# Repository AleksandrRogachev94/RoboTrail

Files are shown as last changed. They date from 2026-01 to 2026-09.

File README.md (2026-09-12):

# RoboTrail 🤖

A Raspberry Pi robot that maps a room by itself, built from parts rather than from a kit — pose-graph SLAM, frontier exploration, and a single time-of-flight rangefinder on a hobby servo standing in for a lidar. No ROS, no gmapping, no Cartographer.

<p align="center">
  <video src="https://github.com/user-attachments/assets/6f5a3e32-c5a6-42ae-8448-716495ea4b60" controls autoplay loop muted playsinline width="100%"></video>
</p>

_Autonomous run: the robot picks a frontier, drives to it, stops, sweeps the room, folds the scan into the pose graph, and repeats — camera streaming the whole time._

## What it actually does

There's no lidar here. The "lidar" is one VL53L1X time-of-flight sensor on a servo, taking 80 readings across a 180° arc every time the robot stops. Against a real spinning scanner that's a sparse, noisy, half-blind view of the room — it costs a rounding error of what a lidar does, and it makes everything downstream harder. That difficulty is most of what makes the project interesting.

Nothing came out of a box. Components were picked one at a time and wired by hand, the chassis and camera mount were modelled in CAD and printed, and every algorithm below — scan matching, the graph optimizer, the exploration planner — is written directly against numpy and scipy rather than pulled from a SLAM library.

The loop is stop-and-scan: drive one waypoint, stop, sweep, match the scan against the previous one, record it as a node in a pose graph, optimize the graph, rebuild the map from the corrected poses, pick the next frontier.

Localization is **pose-graph based, not filter based**. There's no EKF or particle filter in the running system — corrections come from ICP scan matching and joint graph optimization instead. ([EKF_GUIDE.md](EKF_GUIDE.md) is background reading from the learning path, not a description of what's running.)

> **AI assistants:** see [AI_GUIDE.md](AI_GUIDE.md) — the point of this repo is learning robotics, so teach concepts rather than writing the implementation.

## Hardware

<p align="center">
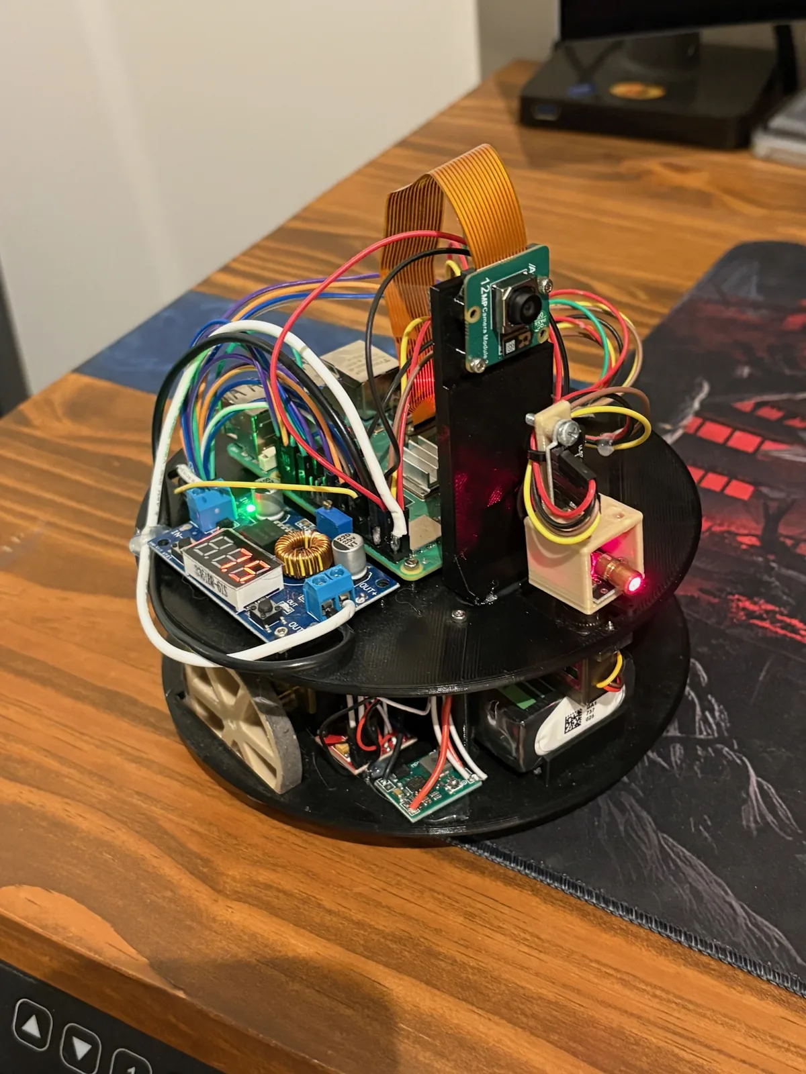
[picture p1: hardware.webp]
RoboTrail — Pi 5, camera, buck converter and ToF laser on the top plate
  
</p>

| Part | Notes |
| --- | --- |
| Raspberry Pi 5 | Runs everything on-board — SLAM, motor control, and the web server |
| Custom 3D-printed chassis | Two-tier round platform, ~155 mm across, SMARS-style tank treads |
| N20 motors + TB6612FNG | 1 kHz software PWM; quadrature encoders counted by the kernel `rotary-encoder` overlay and read over `evdev`, since Python polling drops ticks |
| VL53L1X ToF | Short-range mode, 50 ms timing budget. Readings past 250 cm are treated as "nothing there" rather than as hits |
| SG90 servo | Hardware PWM on GPIO 18 — software PWM jitters under load and smears the scan |
| MPU-6050 | Gyro Z only, integrated at 50 Hz for heading; bias re-calibrated before every move |
| Pi Camera v3 | MJPEG stream to the dashboard, on a [printed mount](cad/pi_camera_v3_mount.scad) |
| KY-008 laser | Debug aid — shows where the ToF is actually pointing |
| 2S LiPo + XL4015 | 7.4 V pack, bucked down to 5 V |

Chassis dimensions, wiring, and I2C addresses are in [CHASSIS.md](CHASSIS.md).

## How it works

**Motion.** Turn in place to face the waypoint, then drive straight. Each wheel runs a velocity PID over a feedforward term (`PWM = 17.8 + 0.07·v`), with a heading PID on top trimming the difference, all at 50 Hz on trapezoidal ramps. Pose is dead-reckoned from encoder ticks using RK2 integration against the midpoint heading.

**Mapping.** A log-odds occupancy grid at 2 cm resolution. Each scan point casts a Bresenham ray: cells along the ray lose 0.4, the cell at the hit gains 0.85, and values clamp at ±5 so the map can still be argued out of a mistake.

**Scan matching.** [`icp.py`](src/icp.py) is a hybrid point-to-line ICP. Surface normals are estimated from each map point's 6 nearest neighbours, and where they're reliable the solver constrains the scan point to lie _on_ the wall rather than on top of one specific map dot — which matters enormously when a scan is only 80 points. Where normals are unreliable it falls back to classic point-to-point SVD. Correspondences past a distance threshold get dropped, and a match ratio below 25% aborts the alignment entirely. Derivations in [ICM_SCAN_MATCHING.md](ICM_SCAN_MATCHING.md).

**Pose graph.** ([`pose_graph.py`](src/pose_graph.py), [GRAPH_SLAM_GUIDE.md](GRAPH_SLAM_GUIDE.md).) Every scan becomes a node, stored in _sensor_ frame so it can be replayed later at a corrected pose. Edges come from odometry, sequential ICP, and loop closures, each weighted by an information matrix derived from match ratio and residual error. `scipy.optimize.least_squares` with a `soft_l1` loss and a sparse Jacobian solves all poses jointly, anchored on node 0; the map is then discarded and rebuilt from the corrected trajectory. That runs every 5 nodes, or immediately when a loop closes.

Most of the work is in the guards around that pipeline:

- An ICP result that disagrees with odometry by more than 10 cm or 20° is rejected outright. Driving alongside a long blank wall, ICP hits the aperture problem — great-looking match, rotation correct, translation off by half the wall — so match quality alone can't be trusted.
- Loop closures need a 5-node gap, a candidate within 70 cm, a heading gap under 90° (with a 180° field of view, two scans facing away from each other share no visible geometry, so a confident match between them is a lie), and an ICP match ratio of 0.6+.
- Turns over 60° trigger a mid-turn scan, because a 90° turn otherwise leaves consecutive scans with almost no overlap for ICP to work with.

**Exploration.** Frontier cells — traversable cells touching unknown space — are clustered by BFS flood fill, with clusters under 30 cells dismissed as noise. Obstacles are inflated by the robot radius (7.75 cm) plus 5 cm of padding, then A\* on the 8-connected grid plans a route, simplified afterwards by line-of-sight checks. The robot drives exactly **one** waypoint per iteration and re-detects frontiers after every scan, so it never keeps chasing a frontier the last scan already resolved. When no reachable frontiers remain, the run is done.

## Web dashboard

[`web_server.py`](src/web_server.py) serves a single page: live camera feed, the occupancy grid on a canvas, and toggleable overlays for traversable space, driven trajectory, planned path, frontier clusters, pose graph nodes and edges, loop closures, and ICP corrections drawn as arrows from raw odometry to the corrected pose. Plus a pose/state HUD, live graph stats, and a PID trace from the last movement. Click the map to send the robot somewhere, or hit Explore and leave it alone.

## Running it

```bash
pip install -r requirements.txt

# on the Pi — needs root for GPIO and port 80
sudo python3 src/web_server.py
```

Then open `http://<pi-ip>` in a browser.

Most modules run standalone off-robot — see the `*_test.py` file next to each one ([`icp_test.py`](src/icp_test.py), [`pose_graph_test.py`](src/pose_graph_test.py), [`path_planner_test.py`](src/path_planner_test.py), [`frontier_test.py`](src/frontier_test.py)); they render plots rather than assert. Calibration lives in the `calibrate_*.py` scripts — ticks per cm, motor feedforward, servo zero, and ToF alignment all need redoing for a different build.

## Docs

| | |
| --- | --- |
| [LEARNING_PATH.md](LEARNING_PATH.md) | The full stage-by-stage build log, dead reckoning through visual SLAM |
| [ICM_SCAN_MATCHING.md](ICM_SCAN_MATCHING.md) | ICP from first principles |
| [GRAPH_SLAM_GUIDE.md](GRAPH_SLAM_GUIDE.md) | Pose graphs, information matrices, loop closure |
| [EKF_GUIDE.md](EKF_GUIDE.md) | Kalman filter background — not used by the current system |
| [CHASSIS.md](CHASSIS.md) | Chassis design, printing, wiring |

## License

MIT

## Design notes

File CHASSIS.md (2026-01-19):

# Chassis Design & 3D Printing Guide

Two-tier platform with tank treads for Raspberry Pi 5 SLAM robot. Design in **Fusion 360**.

```
┌─────────────────────────────┐
│   TOP PLATE                 │  ← Pi 5, sensors, OLED
├─────────────────────────────┤  ← 35mm standoffs (printed)
│   BOTTOM PLATE              │  ← Battery, motors, buck converter
└─────────────────────────────┘
        ◯═══════════◯  ← Tank treads
```

## Dimensions

| Dimension | Value | Notes |
| --- | --- | --- |
| **Chassis length** | 140mm | Fits 2S LiPo battery lengthwise |
| **Chassis width** | 100mm | Stable platform for components |
| **Plate thickness**  | 3-4mm | Rigid but lightweight |
| **Standoff height**  | 35-40mm | Clearance for battery + wiring |
| **Wheel diameter** | 32.5mm | ~2.5 cm/sec with 28BYJ-48 steppers |
| **Wheelbase** | ~90mm | Motor/idler center to center |
| **Motor from edge**  | ~25mm | Required for 45mm mounting wall |
| **Track links** | 15-17 per side | 30-34 total (std SMARS: 32) |
| **Track link pitch** | 17.4mm | Length per link (from STL) |

## Component Dimensions (for Fusion 360 CAD)

### 28BYJ-48 Stepper Motor

```
        ┌───┐ ← Shaft: 5mm with flats, 6mm tall
    ┌───┴───┴───┐
    │  ○     ○  │ ← Mounting holes: 35mm apart, M2 threads
    │    28mm   │ ← Body diameter
    └───────────┘
    Height: 19mm (body only)
    Wiring: 5-pin connector, exits from side
```

### SG90 Micro Servo

```
    ┌─────────────────┐
    │  ┌───┐          │ ← Shaft: 4.8mm, centered 5mm from edge
    ├──┤   ├──────────┤ ← Mounting tabs: 32mm total, 2mm holes
    │  └───┘          │
    └─────────────────┘
    Body: 23mm × 12mm × 22mm
    Tab thickness: 2.5mm each side
```

### Raspberry Pi 5

```
    Mounting holes: 58mm × 49mm (M2.5 standard, but M2 works)
    Board: 85mm × 56mm
    Height with heatsink: ~15mm
```

### Integrated Standoffs (Bottom Plate)

Print standoffs as part of the bottom plate—no separate pieces needed:

```
    Side view (cross-section):

            Top plate (3mm)
    ════════╪════════╪════════  ← Screws down into standoffs
            ║        ║
            ║  35mm  ║  ← Integrated standoffs
            ║        ║
    ┌───────╨────────╨───────┐
    │     Bottom plate       │  (4mm thick)
    └────────────────────────┘
```

**Standoff positions:**

- **Front standoffs:** 5mm from front edge (no motor interference)
- **Rear standoffs:** 30mm from rear edge (clears motor mounting zone)

In Fusion 360: Extrude 8mm diameter cylinders (35mm tall) from corner positions. Use 5mm inset for front corners, 30mm inset for rear corners. Add M2 screw holes (2.2mm) at the top.

### Pi Mounting Bosses (Top Plate)

The Pi needs ~5mm clearance from the plate for airflow and to avoid shorts. Print small bosses integrated into the top plate:

```
    Top plate cross-section:

    ┌────╥────────────────╥────┐
    │    ║ 5mm            ║    │  ← Bosses
    │    ╨                ╨    │
    │        [  Pi 5  ]        │  ← Board sits on bosses
    └──────────────────────────┘

    Boss: 5mm tall, 6mm diameter, M2 hole (2.2mm) centered
    Pattern: 58mm × 49mm (matches Pi mounting holes)
```

### Corner Walls for Wheels

Add small vertical walls at all 4 corners to mount drive wheels and idlers:

```
┌─────────────────────────────────┐
│▓▓│                          │▓▓│ ← Idler mounts (front)
│  │                          │  │
│  │      [flat plate]        │  │
│  │                          │  │
│▓▓│                          │▓▓│ ← Motor mounts (rear)
└─────────────────────────────────┘

Wall dimensions:
- Height: ~45mm (to fit 35mm motor mounting hole spacing + margins)
- Thickness: 2-3mm
- Position: Centered ~25mm from front/rear edges
```

**Tip:** Import SMARS corner brackets from official STL to ensure wheel alignment.

## Parts List

### All 3D Printed

| Part | Quantity | Notes |
| --- | --- | --- |
| Top plate (140×100×3mm) | 1× | With Pi bosses, servo slot, sensor holes |
| Bottom plate with standoffs | 1× | 4mm plate + 35mm integrated corner standoffs |
| Modified wheel (5mm shaft)  | 4× | Search "SMARS 28BYJ-48 wheel" |
| Track links | 40-44× | Print extras for tension adjustment |

> ⚠️ **Important:** Standard SMARS wheels are for DC motors (3mm D-shaft). The 28BYJ-48 stepper has a 5mm shaft with flats. Use modified wheels or edit the STL in Fusion 360.

### Hardware (Buy)

| Part | Quantity | Notes |
| --- | --- | --- |
| M2 × 6mm screws | 16× | For Pi, servo, plates |
| M2 × 8mm screws | 8× | For standoffs to plates |
| M2 nuts | 16× | Or use heat-set inserts |

> **M2 screw length:** 8mm works for most applications. Avoid 5mm—too short for some mounts.

## Print Settings

| Setting | Value | Notes |
| --- | --- | --- |
| **Material** | PLA or PETG | PLA easier, PETG more durable |
| **Layer height** | 0.2mm | Speed/quality balance |
| **Infill** | 20-30% | Plates need rigidity |
| **Walls** | 3 | Strong mounting holes |

**Standoffs:** Print vertically, 40-50% infill for strength.

**Track links:** Print in PLA at 100% infill (or TPU if available). Connect with 1.75mm filament scraps as pins.

## Layout

### Motor Configuration

**Use rear drive** (both motors at rear corners):

- Simpler wiring—both ULN2003 drivers together
- Symmetric and easier to debug
- Better for 140mm chassis (diagonal drive was for compact SMARS)

### Bottom Plate

Motors mount at **rear** corners. Battery runs lengthwise in the center.

```
                  FRONT
    ┌─────────────────────────────────┐
    │  ○                           ○  │  ← Standoffs (front)
    │                                 │
    │   [INA219]   [BUCK CONVERTER]   │  ← Power monitoring + regulation
    │                                 │
    │         ┌─────────────┐         │
    │         │   BATTERY   │         │  ← Battery: 130mm long
    │         │  (2S LiPo)  │         │     centered, runs front-back
    │         └─────────────┘         │
    │                                 │
    │  ┌─────┐             ┌─────┐   │
    │  │MOTOR│             │MOTOR│   │  ← Motors (rear)
    │  │ L   │             │  R  │   │
    │  └─────┘             └─────┘   │
    │  ○                           ○  │  ← Standoffs (rear)
    └─────────────────────────────────┘
                  REAR
```

### Battery Mounting

Use a 4-wall pocket to hold the battery in place:

```
Top view of battery pocket:
┌──────────────────────────────────────┐
│                                      │
│      ┌───────────────────┐           │
│      │                   │← Wall     │
│   ┌──┤                   ├──┐        │
│   │  │     BATTERY       │  │        │
│   │  │                   │  │        │
│   └──┤   ═══════════     ├──┘        │
│      │       ↑           │           │
│      └───────┼───────────┘           │
│              │                       │
│         Wire slot                    │
└──────────────────────────────────────┘

Wall height: ~15mm (just above battery thickness)
Wall thickness: 2-3mm
Wire slot: 10mm wide gap in one wall
```

### Top Plate

Servo+ToF mounts at **front center** for unobstructed 180° scanning. Pi is centered with sensors around it.

```
                  FRONT
    ┌─────────────────────────────────┐
    │  ○        [SERVO+ToF]        ○  │  ← Servo CENTER-FRONT
    │              ↑                  │     (not corner!)
    │         Scanning arc            │
    │                                 │
    │      ┌───────────────┐          │
    │      │  Raspberry    │  [OLED]  │
    │      │     Pi 5      │          │
    │      └───────────────┘          │
    │                        [IMU]    │
    │  ○                           ○  │
    └─────────────────────────────────┘
                  REAR
```

## Fusion 360 Design Tips

1. **Start with sketches**: Create top and bottom plate outlines as 2D sketches before extruding
2. **Use components**: Make each part (plate, standoff, servo mount) a separate component
3. **Parametric design**: Use parameters for key dimensions (plate size, standoff height, screw size) so you can adjust easily
4. **Check clearances**: Use section analysis to verify standoff height provides enough battery clearance
5. **Import SMARS parts**: Import the SMARS chassis STL, extract corner brackets for motor/idler mounts
6. **Export as STL**: Right-click component → Save As Mesh → STL format for slicing

### Recommended Parameters

| Parameter | Value | Description |
| --- | ----- | --- |
| `plate_length` | 140 | Overall chassis length |
| `plate_width`  | 100 | Overall chassis width |
| `standoff_h` | 35 | Standoff height |
| `screw_dia` | 2.0 | M2 screw hole diameter |
| `screw_clear`  | 2.2 | M2 clearance hole diameter |
| `front_inset`  | 5 | Front standoff inset |
| `rear_inset` | 30 | Rear standoff inset |
| `motor_inset`  | 25 | Motor center from edge |

## Checklist Before Printing

1. Print all parts and assemble track chains (18-19 links per side)
2. Mount motors to bottom plate rear using SMARS motor mount brackets
3. Press-fit wheels onto 5mm motor shafts
4. Attach idler wheels at front corners using SMARS idler mounts
5. Loop tracks around drive and idler wheels
6. Insert M2 screws through standoffs and attach to bottom plate (or let self-tap)
7. Mount battery in pocket on bottom plate
8. Mount buck converter on bottom plate
9. Attach top plate to standoffs
10. Mount Pi 5 on bosses, servo (front center), and sensors
11. Wire everything (I2C bus, motor drivers, power)

## Checklist Before Printing

- [ ] Servo mount is centered at front (not corner)
- [ ] Motors are at rear, not front
- [ ] Pi 5 mounting holes match 58×49mm pattern
- [ ] Pi bosses are 5mm tall
- [ ] Standoffs are integrated into bottom plate (35mm tall)
- [ ] Plate holes match component mounting patterns
- [ ] Wheel hub fits 5mm shaft with flats (not 3mm D-shaft)
- [ ] Battery pocket has 4 walls with wire slot
- [ ] Corner walls added for motor and idler mounts

## Resources

- [SMARS Official](https://www.smarsfan.com/) — Original design files
- [Thingiverse SMARS](https://www.thingiverse.com/thing:2662828) — STL downloads
- Search: "SMARS 28BYJ-48" for stepper-compatible wheels

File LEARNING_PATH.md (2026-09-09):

# Learning Path

The full stage-by-stage build log for RoboTrail — see [README.md](README.md) for the project overview and demo. This doc is the original from-scratch walkthrough: hardware, wiring, and every SLAM concept in the order they were actually learned and implemented, from open-loop dead reckoning up through particle filters and visual SLAM.

> **Note for AI:** Follow [AI_GUIDE.md](AI_GUIDE.md) when assisting with this project. Prioritize teaching over implementing.

## Hardware

### Core Components

| Component | Model | Purpose |
| --- | --- | --- |
| **Computer** | Raspberry Pi 5 | Main processing |
| **Chassis** | SMARS (3D printed) | Robot frame |
| **Motors** | N20 + TB6612FNG | DC motors with encoders for odometry |
| **Distance Sensor** | VL53L1X ToF | Laser ranging up to 4m (the "lidar") |
| **IMU** | MPU-6050 | Gyroscope for rotation tracking |
| **Servo** | SG90 | Pan the ToF sensor for 180° scans |

### Power System

| Component | Spec |
| --- | --- |
| **Battery** | 7.4V 5200mAh 2S LiPo |
| **Buck Converter** | XL4015 5A (with voltmeter) |
| **Safety** | Inline blade fuse (5A) |
| **Connector** | Deans/T-plug |
| **Monitoring** | INA219 (I2C voltage/current sensor) |

### Optional Extras

- **SSD1306 OLED** (0.96" I2C) — Display status, battery %, sensor data
- **KY-008 Laser** — Visual debugging (shows where ToF is pointing)

## Learning Path

**SLAM = Simultaneous Localization and Mapping**

SLAM answers two questions at once: _"Where am I?"_ (localization) and _"What does this place look like?"_ (mapping).

**Your Background:** You are comfortable with math/probability (matrices, Bayes rule) but "rusty."
**Our Approach:** We will start with a **deterministic** version (Stage 4) to build intuition for the mechanics. Once that works, we will leverage your math background to upgrade to **Probabilistic SLAM** (Stage 4.5/5), implementing proper uncertainty handling (Bayesian filters) which is the "real" way robotics is done.

**Stages 1-3** teach you the building blocks. **Stage 4** is where you actually do SLAM. **Stage 5** adds intelligence on top.

---

### Stage 1: Open-Loop Movement (Foundation)

**Goal:** Make the robot drive in a perfect 1-meter square.

**What you'll learn:** How stepper motors work, basic motor control, differential turning, the concept of dead reckoning.

- Write Python to control steppers via ULN2003
- Tune `STEPS_PER_CM` until forward distance is accurate
- Tune `STEPS_PER_DEGREE` for precise 90° turns (differential drive: one wheel forward, one backward)
- Combine straight + turn movements to close the square perfectly
- No sensors yet—pure dead reckoning (counting steps to estimate distance and rotation)

**Why it matters:** Dead reckoning is the foundation of knowing "how far did I move?" and "how much did I turn?" Even with sensors, you need this as a starting estimate.

---

### Stage 2: Virtual Scanner (Sensing)

**Goal:** Create a visual radar plot of the room.

**What you'll learn:** How ToF ranging works, polar-to-cartesian conversion, basic visualization.

- Mount VL53L1X on servo
- Sweep 180° taking measurements every 10°
- Plot with matplotlib—should show room outline

**Why it matters:** This is the "mapping" half of SLAM. You're collecting range data that becomes walls on your map.

---

### Stage 3: DC Motors & PID Control

**Goal:** Upgrade to DC motors with encoder feedback and PID control for accurate movement.

**What you'll learn:** Encoder-based odometry, PID velocity control, IMU sensor fusion, control loop architecture.

#### Hardware Changes

| Component | Purpose |
| --- | --- |
| **N20 motors with encoder** | 6V, 150RPM, AB hall encoder (~20 cm/sec at 5V) |
| **TB6612FNG driver** | Efficient H-bridge for PWM motor control |

#### Pi 5 Encoder Setup

Use kernel-level encoder counting (Python polling is too slow):

```bash
# /boot/firmware/config.txt
dtoverlay=rotary-encoder,pin_a=17,pin_b=18,relative_axis=1  # Left motor
dtoverlay=rotary-encoder,pin_a=22,pin_b=23,relative_axis=1  # Right motor
```

Read encoder position from `/dev/input/eventX` using the `evdev` library.

#### Control Architecture

For stop-and-scan SLAM, a simple **single-threaded blocking** approach works best:

```python
class MotionController:
    def move(self, distance_cm, heading):
        """Blocking: PID runs inside until distance reached."""
        target_ticks = distance_cm * TICKS_PER_CM
        start = self.encoder.total

        while (self.encoder.total - start) < target_ticks:
            # Heading PID
            correction = self.heading_pid.update(heading - self.imu.heading)

            # Velocity PIDs
            left_pwm = self.left_pid.update(self.left_enc.velocity, speed - correction)
            right_pwm = self.right_pid.update(self.right_enc.velocity, speed + correction)
            self.motors.set(left_pwm, right_pwm)

            time.sleep(0.01)  # 100 Hz

        self.motors.stop()
        # Returns when done

def slam_loop():
    motion = MotionController()
    while exploring:
        motion.move(30, heading)     # Blocking - PID runs inside
        scan = scanner.sweep_180()   # Robot stopped
        pose = icp_correct(scan)     # SLAM processing
        update_map(scan, pose)
        heading = plan_next()
```

#### Three PIDs Working Together

| PID | Input | Output | Purpose |
| --- | --- | --- | --- |
| **Left velocity**  | Left encoder rate  | Left motor PWM | Track target velocity |
| **Right velocity** | Right encoder rate | Right motor PWM | Track target velocity |
| **Heading** | IMU gyro heading | Velocity difference | Keep robot straight |

**Key difference from steppers:** Encoders tell you how far you _actually_ moved, not how far you _commanded_. This is true closed-loop control.

**Why it matters for SLAM:** Accurate odometry = better pose prediction = better scan matching = better maps.

#### Arc Movement for Path Following

The robot cannot reliably rotate in place (friction causes stuttering), so we use **arc motion** where both wheels move forward at different speeds.

**Path pipeline:**

1. **A\*** on occupancy grid → raw path
2. **Gradient descent smoothing** (Sebastian Thrun's method) → smooth waypoints
3. **Arc-to-waypoint** geometry → compute arc from current pose to next waypoint
4. **Execute arc()** → differential wheel velocities

**Key formula** - Arc to reach point (x', y') from pose (x, y, θ):

```python
# Transform target to robot frame
local_x = dx * cos(θ) + dy * sin(θ)  # forward
local_y = -dx * sin(θ) + dy * cos(θ)  # left

# Arc radius (positive = left turn)
radius = (local_x² + local_y²) / (2 * local_y)
```

**Wheel velocities for arc:**

```python
v_left  = v_center * (1 - 1/radius * track_width/2)
v_right = v_center * (1 + 1/radius * track_width/2)
```

---

### Stage 4: Occupancy Grid (This is SLAM!)

**Goal:** Build a persistent map while tracking your position.

**What you'll learn:** Occupancy grids, coordinate transforms, scan matching, the predict-correct loop.

#### The Predict-Correct Loop

SLAM continuously runs this cycle:

```
┌─────────────────────────────────────────────────────────────┐
│  1. PREDICT: "Based on my motor commands, I should be here" │
│     └─ Use: Stepper counts + Gyro heading                   │
│                          ↓                                  │
│  2. SCAN: "What do I see around me?"                        │
│     └─ Use: ToF sensor swept by servo (18 points @ 10°)     │
│                          ↓                                  │
│  3. CORRECT: "Does this scan match what the map says?"      │
│     └─ If wall in map is 2cm left of where I expected →     │
│        I must be 2cm right of where I thought               │
│                          ↓                                  │
│  4. UPDATE: Add new walls to map, mark free space           │
│                          ↓                                  │
│  5. PLAN: Where should I go next? (find unexplored area)    │
│                          ↓                                  │
│  6. MOVE: Execute movement → back to step 1                 │
└─────────────────────────────────────────────────────────────┘
```

#### How Each Sensor Is Used

| Sensor | Role in SLAM |
| --- | --- |
| **Encoders** | PREDICT: "Wheels moved 200 ticks = ~10cm" |
| **Gyro (MPU-6050)** | PREDICT: "I rotated 45° during that turn" |
| **ToF (VL53L1X)** | SCAN: "Wall is 87cm away at angle 30°" |
| **Servo** | SCAN: Points the ToF at different angles  |

#### How Scanning Works

```python
def scan():
    points = []
    for angle in range(0, 181, 10):  # 0°, 10°, 20°... 180°
        servo.angle = angle
        time.sleep(0.1)  # Let servo settle
        distance = tof.read()
        points.append((angle, distance))
    return points  # 19 points forming a semicircle view
```

Each scan gives you ~19 points. Convert to map coordinates:

```python
for angle, distance in points:
    # Convert polar (angle, distance) to cartesian (x, y)
    world_angle = robot_heading + angle  # Absolute angle
    x = robot_x + distance * cos(world_angle)
    y = robot_y + distance * sin(world_angle)
    map[x][y] = WALL  # Mark as occupied
```

#### How Correction Works (Simplified)

```python
# After scanning, compare to existing map
expected_wall_distance = map.ray_cast(robot_x, robot_y, angle)
actual_wall_distance = tof.read()

error = actual_wall_distance - expected_wall_distance
# If error > 0: wall is further than expected → I'm closer to it
# If error < 0: wall is closer than expected → I'm further from it

robot_x += error * cos(angle)  # Nudge position estimate
robot_y += error * sin(angle)
```

This is a simplified version. Real SLAM uses algorithms like:

- **ICP** (Iterative Closest Point) — matches scan points to map
- **Particle Filter** — maintains multiple position hypotheses
- **Kalman Filter** — probabilistic state estimation

For learning, start with the simple version above!

#### Handling Scan Gaps

With 10° angular resolution, walls will have gaps between points. Start simple—multiple scans from different positions naturally fill gaps as evidence accumulates. If scan matching becomes jittery, add **distance-threshold interpolation** (fill between similar-distance readings). If A\* paths clip walls, add **inflation** (mark cells near obstacles as blocked).

#### How the Robot Explores

**Frontier-Based Exploration:**

1. Find cells in the map that are "unknown" (never scanned)
2. Find "frontiers" = boundaries between known-free and unknown
3. Drive toward the nearest frontier
4. Repeat until no frontiers remain (room fully mapped)

```
Map:  ? = unknown, . = free, # = wall

  ? ? ? ? ? ?
  ? . . . ? ?    Robot sees frontier at top-right
  ? . @ . ? ?    @ = robot position
  ? . . . # ?    Drives toward "?" to explore
  ? # # # # ?
```

#### Path Planning with A\*

Once you know _where_ to go (frontier), you need to plan _how_ to get there while avoiding obstacles.

**A\* Algorithm:** Finds the shortest path on your occupancy grid.

```python
def a_star(grid, start, goal):
    open_set = PriorityQueue()
    open_set.put((0, start))
    came_from = {}
    g_score = {start: 0}

    while not open_set.empty():
        _, current = open_set.get()

        if current == goal:
            return reconstruct_path(came_from, current)

        for neighbor in get_neighbors(grid, current):
            tentative_g = g_score[current] + 1
            if tentative_g < g_score.get(neighbor, inf):
                came_from[neighbor] = current
                g_score[neighbor] = tentative_g
                f_score = tentative_g + heuristic(neighbor, goal)
                open_set.put((f_score, neighbor))

    return None  # No path found
```

**Heuristic:** Use Euclidean or Manhattan distance to the goal. A\* guarantees the shortest path if the heuristic never overestimates.

#### What You'll Build

- `occupancy_grid.py` — 2D numpy array representing the map
- `scanner.py` — Sweep servo, collect ToF readings
- `localizer.py` — Predict position, correct with scan matching
- `path_planner.py` — A\* implementation for obstacle avoidance
- `explorer.py` — Find frontiers, use A\* to plan paths
- `main.py` — The loop that ties it all together

---

### Stage 5: Extended Kalman Filter (Probabilistic)

**Goal:** Replace deterministic position tracking with probabilistic state estimation.

**What you'll learn:** Gaussian uncertainty, covariance matrices, the predict-update cycle, sensor fusion via Kalman gain.

**Why EKF?** Stage 4 uses simple correction ("nudge position by error"). This works but doesn't track _how confident_ you are. EKF maintains a probability distribution over your position—uncertainty grows when moving, shrinks when sensing.

#### The EKF Loop

```python
# State: [x, y, θ] with covariance P (3×3 matrix)

def predict(motor_command):
    # Update state estimate
    x += distance * cos(θ)
    y += distance * sin(θ)
    θ += gyro_reading

    # Uncertainty GROWS (process noise Q)
    P = F @ P @ F.T + Q

def update(scan):
    for measurement in scan:
        expected = ray_cast(x, y, θ + angle)
        innovation = measurement - expected

        # Kalman gain: balance prediction vs measurement trust
        K = P @ H.T @ inv(H @ P @ H.T + R)

        # Correct state
        state += K @ innovation

        # Uncertainty SHRINKS
        P = (I - K @ H) @ P
```

#### Key Concepts

| Concept | Meaning |
| --- | --- |
| **State vector** | `[x, y, θ]` — what we're estimating |
| **Covariance (P)** | How uncertain we are about each state variable |
| **Process noise (Q)** | How much uncertainty motion adds |
| **Measurement noise (R)** | How noisy the ToF sensor is |
| **Kalman gain (K)** | How much to trust sensor vs prediction |
| **Jacobian (F, H)** | Linearization for nonlinear models |

#### What You'll Build

- `ekf.py` — EKF state estimation class
- Modify `localizer.py` to use EKF instead of simple correction
- Tune Q and R matrices for your hardware

---

### Stage 6: Particle Filter (Multi-Hypothesis)

**Goal:** Handle ambiguous situations where EKF fails (symmetry, kidnapping, global localization).

**What you'll learn:** Monte Carlo methods, importance sampling, resampling, representing arbitrary probability distributions.

**Why Particle Filter?** EKF assumes a single Gaussian belief. If the robot could be in multiple places (identical hallways, placed in unknown location), EKF can't represent this. Particles can.

#### The Particle Filter Loop

```python
# Particles: N samples, each is (x, y, θ, weight)
particles = initialize_uniform(N=100)

def predict(motor_command):
    for p in particles:
        # Move each particle with noise
        p.x += distance * cos(p.θ) + random.gauss(0, σ_motion)
        p.y += distance * sin(p.θ) + random.gauss(0, σ_motion)
        p.θ += gyro_reading + random.gauss(0, σ_rotation)

def update(scan):
    for p in particles:
        # Score: how well does this particle explain the scan?
        p.weight = 1.0
        for angle, distance in scan:
            expected = ray_cast(p.x, p.y, p.θ + angle)
            error = (distance - expected) ** 2
            p.weight *= exp(-error / (2 * σ_sensor²))

    # Normalize weights
    total = sum(p.weight for p in particles)
    for p in particles:
        p.weight /= total

    # Resample: keep good particles, discard bad ones
    particles = resample(particles)

def get_estimate():
    # Weighted average of all particles
    return (sum(p.x * p.weight), sum(p.y * p.weight), ...)
```

#### Key Concepts

| Concept | Meaning |
| --- | --- |
| **Particle** | One hypothesis of robot pose |
| **Weight** | How likely this hypothesis is given sensor data |
| **Resampling**  | Clone good particles, delete bad ones |
| **Multimodal**  | Can represent multiple possible locations |
| **Convergence** | Particles cluster at true location over time |

#### When to Use Each

| Scenario | Use |
| --- | --- |
| Known start, building map | EKF (efficient, accurate) |
| Unknown start, known map  | Particle (global localization) |
| Kidnapped robot recovery  | Particle (redistribute hypotheses) |
| Symmetric environments | Particle (multiple hypotheses) |

#### What You'll Build

- `particle_filter.py` — Particle filter class
- Modify `localizer.py` to switch between EKF and particle mode
- Implement resampling strategies (systematic, low-variance)

#### A Note on Loop Closure

Neither EKF nor particle filters solve **loop closure** — detecting when you've returned to a previously visited area. Small scan-matching errors accumulate over time, so your map may not "close" properly:

```
Start → explore → return to start
        ↓
Map shows you 10cm away from where you actually started!
```

**Detection:** Compare current scan to stored scan from that area. High similarity = loop detected.

**Correction:** Requires **graph-based SLAM** (e.g., g2o, GTSAM) to optimize the entire trajectory. This is an advanced topic beyond the current stages but worth knowing exists.

For room-sized exploration, accumulated error is usually small enough that loop closure isn't critical. For larger spaces or repeated runs, it becomes essential.

---

### Stage 7: Semantic Localization (Advanced)

**Goal:** Recognize _where_ you are using visual landmarks.

**What you'll learn:** Object detection, landmark-based localization, loop closure.

- Run YOLO on Pi Camera
- When detecting objects (chair, door), save their location to the map
- Use landmarks for relocalization if robot gets lost

**Why it matters:** Pure geometric SLAM can get confused in similar-looking corridors. Recognizing "I see the red chair" gives absolute position references.

---

### Stage 8: Visual SLAM (Feature-Based)

**Goal:** Full camera-based SLAM using visual features instead of (or alongside) ToF.

**What you'll learn:** Feature extraction (ORB, SIFT), descriptor matching, visual odometry, bundle adjustment, loop closure detection.

**The idea:** Extract distinctive points from camera images, track them across frames to estimate motion, and build a 3D map of feature locations. This is how systems like ORB-SLAM work.

**Why it's the final stage:** Combines everything—probabilistic state estimation, sensor fusion, and now replaces the ToF "lidar" with pure vision.

---

## I2C Wiring

I2C is a 2-wire bus that lets multiple devices share the same connection. Each device has a unique address.

### Physical Connection

```
Raspberry Pi 5          All I2C Devices (shared bus)
─────────────           ─────────────────────────────
GPIO 2 (SDA) ──────────┬── VL53L1X SDA
                       ├── MPU-6050 SDA
                       ├── INA219 SDA
                       └── SSD1306 SDA

GPIO 3 (SCL) ──────────┬── VL53L1X SCL
                       ├── MPU-6050 SCL
                       ├── INA219 SCL
                       └── SSD1306 SCL

3.3V ──────────────────┬── VL53L1X VCC
                       ├── MPU-6050 VCC
                       ├── INA219 VCC
                       └── SSD1306 VCC

GND ───────────────────┬── VL53L1X GND
                       ├── MPU-6050 GND
                       ├── INA219 GND
                       └── SSD1306 GND
```

### I2C Addresses (Default)

| Device | Address |
| --- | --- |
| VL53L1X  | 0x29 |
| MPU-6050 | 0x68 |
| INA219 | 0x40 |
| SSD1306  | 0x3C |

All different, so no conflicts! Run `i2cdetect -y 1` on the Pi to see connected devices.

## Main Loop Strategy: Stop-and-Scan

```
1. Move    → Drive forward using dead reckoning + gyro correction
2. Stop    → Every 50cm, halt completely
3. Scan    → Sweep servo 180° to gather ToF measurements
4. Update  → Add walls to occupancy grid, correct position
5. Plan    → Find unexplored areas, drive toward them
```

## Key Concepts

| Concept | What It Means |
| --- | --- |
| **Dead Reckoning**  | Estimating position by counting motor steps |
| **Sensor Fusion** | Combining multiple sensors for better accuracy |
| **PID Controller**  | Feedback loop to minimize error (drift correction) |
| **Occupancy Grid**  | 2D array representing free/occupied space |
| **ZUPT** | Zero-Velocity Update—recalibrate gyro when stationary |
| **Sensor Sampling** | Read gyro/encoders at 50Hz+ to capture all motion |

> [!IMPORTANT] > **Gyro and Encoder Sampling Rate**
>
> Gyros output _instantaneous angular rate_ (deg/sec), not accumulated rotation. To know total rotation, you must integrate: `total = ∫ rate(t) dt`. If you sample too slowly, you miss rotation that happened between samples (**aliasing**).
>
> **Example:** Robot turns for 1 second, then goes straight for 1 second.
>
> - Sample at 50Hz: Captures turn → integrates to 20° ✅
> - Sample at end only: Reads 0°/s × 2s = 0° ❌
>
> **This applies to ALL algorithms** (dead reckoning, PID, EKF, particle filter). The estimation algorithm can run slowly, but sensor integration must be continuous.
>
> Similarly, DC motor encoders output pulses that must be counted at high rate (hardware interrupt or kernel driver) or pulses are lost.

## Coordinate Systems

SLAM requires converting between three coordinate frames:

```
1. SENSOR FRAME     2. ROBOT FRAME       3. WORLD FRAME
   (ToF reading)       (chassis)            (the map)

      ↑ 0°                ↑ Forward            ↑ North (Y+)
      │                   │                    │
  ←───┼───→           ←───●───→            ←───┼───→ East (X+)
      │               Robot center             │
   Servo angle        (origin)              Map origin
```

### When to Convert

| From → To | When | Formula |
| --- | --- | --- |
| Sensor → Robot | After each ToF reading | Add sensor offset `(x_tof, y_tof)` |
| Robot → World  | When adding points to map | Rotate by heading, add robot position |

### Sensor Position Matters

The ToF sensor is mounted ~7cm in front of robot center. **This offset must be corrected**, otherwise scans from different headings won't align:

```
Facing North: ToF is 7cm closer to north wall → measures 1.93m instead of 2.0m
Facing East:  ToF offset is now horizontal → measures 2.0m correctly

Without correction: same wall appears at y=1.93m and y=2.0m (7cm error!)
```

### Transformation Code

```python
# Sensor offsets (meters from robot center)
TOF_OFFSET_X = 0.0    # Centered left-right
TOF_OFFSET_Y = 0.07   # 7cm forward

def scan_point_to_world(distance, servo_angle, robot_x, robot_y, robot_heading):
    """Convert a single ToF reading to world coordinates."""
    # Sensor frame → Robot frame
    px = distance * cos(servo_angle) + TOF_OFFSET_X
    py = distance * sin(servo_angle) + TOF_OFFSET_Y

    # Robot frame → World frame (rotate + translate)
    world_x = robot_x + px * cos(robot_heading) - py * sin(robot_heading)
    world_y = robot_y + px * sin(robot_heading) + py * cos(robot_heading)
    return world_x, world_y
```

## Servo PWM on Pi 5

Software PWM causes jitter under CPU load. Use **hardware PWM** for reliable servo control:

```bash
# /boot/firmware/config.txt
dtoverlay=pwm-2chan
```

Servo must be on **GPIO 12 or 18** (PWM0) or **GPIO 13 or 19** (PWM1). Use `rpi-hardware-pwm` library:

```python
from rpi_hardware_pwm import HardwarePWM
pwm = HardwarePWM(pwm_channel=0, hz=50, chip=2)  # chip=2 for Pi 5
pwm.start(7.5)  # 7.5% = center (1.5ms pulse)
# 5% = -90°, 10% = +90°
```

**Alternative:** PCA9685 I²C servo driver ($3-5) handles timing externally—16 channels, no GPIO constraints.

## Wiring Overview

### Option A: DC Motors (N20 + TB6612FNG)

| Connection | GPIO/Pin |
| --- | --- |
| **TB6612FNG** | |
| VM | 6V motor supply |
| VCC | 3.3V |
| GND | Common ground |
| STBY | 3.3V (tie high) |
| PWMA | GPIO 12 (right speed, ~1kHz) |
| PWMB | GPIO 16 (left speed, ~1kHz) |
| AIN1 / AIN2 | GPIO 20 / 21 (right direction) |
| BIN1 / BIN2 | GPIO 25 / 24 (left direction)  |
| A01 / A02 | Right motor (red/white) |
| B01 / B02 | Left motor (red/white) |
| **Encoders** | |
| Left encoder A/B  | GPIO 17 / 27 |
| Right encoder A/B | GPIO 5 / 6 |
| Encoder VCC | 3.3V |
| Encoder GND | GND |

> [!NOTE]
> Motors use **software PWM** (lgpio) at ~1kHz to avoid conflict with the servo's hardware PWM on GPIO 18 (50Hz). BIN1/BIN2 are swapped (25/24) to correct left motor direction.

### Option B: Stepper Motors (28BYJ-48 + ULN2003)

| Connection  | GPIO |
| --- | --- |
| Left motor  | GPIO 17, 27, 22, 23 |
| Right motor | GPIO 5, 6, 13, 19 |

### Common Wiring

```
Raspberry Pi 5
├── I2C Bus (GPIO 2/3)
│   ├── VL53L1X (ToF sensor)
│   ├── MPU-6050 (IMU)
│   ├── INA219 (battery monitor)
│   └── SSD1306 (OLED display)
├── Servo (GPIO 18, hardware PWM)
├── KY-008 Laser (optional)
└── Power: 5V from XL4015 buck converter
```

## Resources

- [SMARS Robot](https://www.smarsfan.com/) — Chassis design and mods
- [VL53L1X Datasheet](https://www.st.com/resource/en/datasheet/vl53l1x.pdf)
- [MPU-6050 Guide](https://invensense.tdk.com/products/motion-tracking/6-axis/mpu-6050/)

## License

MIT

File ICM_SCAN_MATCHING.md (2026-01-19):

# ICP Scan Matching: Understanding from First Principles

This guide teaches you the ICP (Iterative Closest Point) algorithm by building intuition for the underlying mathematics. By the end, you'll understand not just _what_ to implement, but _why_ each step works.

---

## Part 1: The Problem We're Solving

Imagine you take a laser scan of a room, drive forward 20cm, and take another scan. You _think_ you moved 20cm, but wheel slip and surface variations mean you might have actually moved 18cm or 22cm. How do you figure out your _true_ motion?

**The insight**: If both scans see the same walls, you can compare them. The transformation (rotation + translation) that makes the second scan "land on top of" the first scan **is** your actual motion.

```
Scan A (before):           Scan B (after):           Aligned:
    • • • •                    • • • •                 • • • •
    •       •                  •       •               ••     ••
    •       •      ──────►     •       •    ──────►    ••     ••
    •       •                  •       •               ••     ••
    • • • •                    • • • •                 • • • •
   (fixed)                   (needs alignment)        (overlapped)
```

The challenge: we don't know which point in Scan B corresponds to which point in Scan A. This is the **correspondence problem**, and it's what makes scan matching tricky.

---

## Part 2: Rigid Transformations in 2D

Before tackling the full algorithm, let's make sure we understand how to describe motion mathematically.

### What Is a Rigid Transformation?

A **rigid transformation** preserves distances and angles—it's pure rotation and translation, no stretching or shearing. When your robot moves, it undergoes a rigid transformation.

Any rigid transformation in 2D can be described by:

- A rotation angle **θ**
- A translation vector **t = [tx, ty]ᵀ**

To transform a point **p** to a new position **p'**:

```
p' = R(θ) · p + t
```

### The Rotation Matrix

Why do we use matrices for rotation? Let's derive it from scratch.

Consider a point **p = [x, y]ᵀ**. We want to rotate it by angle θ around the origin. Using basic trigonometry:

If the original point is at angle φ and distance r from origin:

- x = r·cos(φ)
- y = r·sin(φ)

After rotating by θ, the new angle is (φ + θ), but distance r stays the same:

- x' = r·cos(φ + θ)
- y' = r·sin(φ + θ)

Using the angle addition formulas:

- cos(φ + θ) = cos(φ)cos(θ) - sin(φ)sin(θ)
- sin(φ + θ) = sin(φ)cos(θ) + cos(φ)sin(θ)

Substituting x = r·cos(φ) and y = r·sin(φ):

- x' = x·cos(θ) - y·sin(θ)
- y' = x·sin(θ) + y·cos(θ)

Writing this as a matrix equation:

```
┌ x' ┐   ┌ cos(θ)  -sin(θ) ┐   ┌ x ┐
│    │ = │                 │ · │   │
└ y' ┘   └ sin(θ)   cos(θ) ┘   └ y ┘
```

That's our rotation matrix **R(θ)**.

### Key Properties of Rotation Matrices

**Property 1: Orthogonality (Rᵀ = R⁻¹)**

Rotation doesn't stretch anything—it preserves lengths. Mathematically, this means:

```
RᵀR = I  (identity matrix)
```

This is incredibly useful because inverting a rotation is just transposing it—no expensive matrix inversion needed. To "undo" a rotation by θ, just apply R(-θ) = Rᵀ.

**Property 2: Determinant = 1**

det(R) = cos²(θ) + sin²(θ) = 1

This confirms no stretching or reflection. A reflection would have det = -1.

**Property 3: Rotations Compose by Addition**

R(θ₁) · R(θ₂) = R(θ₁ + θ₂)

You can verify this by multiplying out the matrices and using trig identities.

---

## Part 3: The ICP Algorithm Overview

ICP solves the alignment problem through iteration:

```
1. GUESS: Start with some initial transformation (often from odometry)
2. MATCH: For each point in scan B, find the closest point in scan A
3. SOLVE: Find the best transformation that aligns the matched pairs
4. APPLY: Transform scan B by this transformation
5. REPEAT: Go back to step 2, using the newly transformed B

Stop when the transformation becomes negligibly small (convergence).
```

Why iterate? Because step 2 (finding correspondences) depends on how well aligned the scans are. With a bad initial alignment, you get wrong correspondences. But after aligning a little, correspondences improve, which allows better alignment, and so on.

---

## Part 4: The Alignment Problem (Given Correspondences)

Let's temporarily assume someone gave us correct correspondences—matched pairs of points:

- (b₁, a₁), (b₂, a₂), ..., (bₖ, aₖ)

We want to find R and t that minimize the total squared error:

```
E(R, t) = Σᵢ || aᵢ - (R·bᵢ + t) ||²
```

This is a **least squares** problem. Let's understand why we use squared errors and how to solve it.

### Why Squared Errors?

Consider three candidate transformations with these residual errors for 4 point pairs:

| Transform | Errors | Sum of | errors | | Sum of errors² |
| --- | --- | --- | --- | --- | --- |
| T₁ | [1, 1, 1, 1] | 4 | 4 |
| T₂ | [0, 0, 0, 4] | 4 | 16 |
| T₃ | [0.5, 0.5, 0.5, 0.5] | 2 | 1 |

**Observation 1**: Sum of absolute errors treats T₁ and T₂ equally, but T₂ is worse—it has one terrible match while T₁ is consistently decent.

**Observation 2**: Squaring penalizes large errors more heavily. T₂ gets punished for having a 4-unit error.

**Observation 3**: The function E = Σ(error)² is smooth and differentiable everywhere, making it amenable to calculus-based optimization. Absolute values have a kink at zero.

**Observation 4**: If errors are Gaussian-distributed (which sensor noise often is), minimizing squared error gives the Maximum Likelihood Estimate—the most probable solution.

### Decoupling Rotation and Translation

Here's a key insight that simplifies our problem: **we can solve for rotation first, then translation falls out trivially**.

Define the centroids (centers of mass):

```
μ_a = (1/K) Σᵢ aᵢ    (centroid of the A points)
μ_b = (1/K) Σᵢ bᵢ    (centroid of the B points)
```

Define centered points:

```
a'ᵢ = aᵢ - μ_a
b'ᵢ = bᵢ - μ_b
```

**Theorem**: The optimal rotation minimizes the error between centered points, and the optimal translation is:

```
t* = μ_a - R* · μ_b
```

**Why does this work?** Think about it geometrically. After optimal alignment:

- The centroid of transformed B should land on the centroid of A
- R·μ_b + t = μ_a
- Therefore t = μ_a - R·μ_b

By centering, we remove the translation component entirely from the rotation optimization. Now we just need to find R that minimizes:

```
Σᵢ || a'ᵢ - R·b'ᵢ ||²
```

---

## Part 5: Understanding SVD (The Heart of the Solution)

Singular Value Decomposition is one of the most powerful tools in linear algebra. Let's build intuition for what it does.

### What Does a Matrix DO?

Any matrix M represents a linear transformation. When you multiply M by a vector, you're transforming that vector.

Consider what happens when you apply a 2×2 matrix to the unit circle (all vectors of length 1):

```
Unit circle → [Matrix M] → Ellipse
```

The circle gets stretched into an ellipse. This is true for _any_ matrix (except the zero matrix).

### The Geometry of SVD

SVD says any matrix M can be decomposed as:

```
M = U · Σ · Vᵀ
```

What this means geometrically:

1. **Vᵀ** rotates/reflects the input
2. **Σ** stretches along the coordinate axes
3. **U** rotates/reflects the output

```
Input      Vᵀ           Σ              U           Output
  ○   ──────────►  ○  ──────────►  ⬭  ──────────►   ⬭
circle           rotated        ellipse         rotated
                 circle         (axis-aligned)  ellipse
```

**The singular values** (diagonal of Σ) are the scaling factors—they tell you how much stretching happens in each direction.

**The columns of V** are the input directions that get mapped to the principal axes.

**The columns of U** are the output principal axes.

### Computing SVD: What's Happening?

Let's think about the 2×2 case for our matrix H (the cross-covariance matrix we'll build).

The singular values σ₁, σ₂ are the square roots of the eigenvalues of HᵀH (or HHᵀ).

Wait, what are eigenvalues? If you've forgotten:

**Eigenvalue refresher**: For a square matrix A, an eigenvector v satisfies:

```
A·v = λ·v
```

Multiplying by A just scales v by factor λ (the eigenvalue). The vector points in the same direction.

For a symmetric matrix (like HᵀH), the eigenvectors are orthogonal to each other—they form a natural coordinate system. The eigenvalues tell you how much the matrix "stretches" in each eigenvector direction.

**Connection to SVD**:

- Columns of V are eigenvectors of HᵀH
- Columns of U are eigenvectors of HHᵀ
- Singular values = √(eigenvalues of HᵀH)

In practice, you call `numpy.linalg.svd(H)` and it handles the numerical details.

### Why SVD Solves Our Rotation Problem

Here's the beautiful result. Given our centered points, define:

```
H = Σᵢ b'ᵢ · a'ᵢᵀ
```

This is called the **cross-covariance matrix**. Each term is an outer product:

```
b'ᵢ · a'ᵢᵀ = ┌ b'x ┐            ┌ b'x·a'x  b'x·a'y ┐
             │     │ · [a'x a'y] = │                 │
             └ b'y ┘            └ b'y·a'x  b'y·a'y ┘
```

Summing over all point pairs gives H.

**What does H capture?** It encodes the correlation between the two point sets. If b and a tend to point in similar directions, certain entries of H will be large and positive.

**The SVD magic**: Decompose H = UΣVᵀ. Then:

```
R* = V · Uᵀ
```

### Why Does R = VUᵀ Work?

Let me give you the intuition (not a formal proof, but enough to understand).

Remember what SVD does: H = UΣVᵀ means H takes vectors, rotates by Vᵀ, scales by Σ, then rotates by U.

We want R such that:

```
Σᵢ || a'ᵢ - R·b'ᵢ ||²  is minimized
```

Expanding and simplifying (using properties of traces and orthogonal matrices), this becomes equivalent to:

```
Maximize: trace(RᵀH)
```

The trace of a matrix is the sum of its diagonal elements—it represents a sort of "alignment score" between R and H.

Now, RᵀH = Rᵀ(UΣVᵀ). We want to maximize trace(RᵀUΣVᵀ).

Since Σ is diagonal (with positive entries), and we want to maximize the trace, we need RᵀU = V, which means R = VUᵀ.

**Physical intuition**: U captures how the A points are oriented. V captures how the B points are oriented. VUᵀ is the rotation that maps B's orientation to A's orientation.

### The Reflection Edge Case

SVD gives orthogonal matrices U and V, but orthogonal matrices can be rotations (det = +1) or reflections (det = -1).

If det(VUᵀ) = -1, we got a reflection, not a rotation. Robots don't reflect! To fix this:

```
If det(V · Uᵀ) < 0:
    Flip the sign of the last column of V
    Recompute R = V · Uᵀ
```

This gives the best rotation (not reflection).

---

## Part 6: The Correspondence Problem

We've solved alignment assuming known correspondences. But how do we find correspondences?

### Nearest Neighbor Matching

The simplest approach: for each point bᵢ in scan B, find the closest point in scan A.

```
For each bᵢ:
    corresponding[i] = argmin_j || bᵢ - aⱼ ||
```

This requires computing distances from each B point to every A point—O(N×M) operations.

**When does this work?** When scans are approximately aligned. If B is rotated 90° from A, nearest neighbors will be completely wrong.

**The bootstrap**: Use odometry as initial guess. Odometry might be off by a few cm/degrees, but it's not off by 90°. This gets us close enough for nearest neighbor to work.

### Improving Correspondences with Iteration

Even if initial correspondences are imperfect, they're "approximately right" if the initial guess is decent. Aligning with imperfect correspondences still moves scans closer together.

After alignment, correspondences improve. After a few iterations, they stabilize at the correct matching.

This is why ICP is **iterative**—each iteration improves both alignment and correspondences.

### Outlier Rejection

Some correspondences are just wrong:

- Points that don't have true matches (one scan sees a door, other doesn't)
- Sensor noise creating spurious points
- Moving objects (person walked by during one scan)

Bad correspondences corrupt the alignment. Common fixes:

**Distance threshold**: If |b - closest_a| > threshold, reject the pair. A wall hasn't moved 2 meters between scans.

**Percentage-based**: Keep only the 80% of pairs with smallest distances. Outliers tend to have larger distances.

**Statistical**: Compute mean and std of distances, reject pairs > 2 std from mean.

---

## Part 7: Point-to-Line ICP (An Improvement)

Basic ICP minimizes point-to-point distances. But think about a wall:

```
Scan A:       · · · · · · ·    (points along wall)
Scan B:         · · · · · ·    (shifted along wall)
```

Point-to-point ICP wants each B point to exactly match some A point. But if B is shifted along the wall, points might match to wrong neighbors, causing jitter.

**Point-to-line insight**: Points on a wall can slide along the wall freely—only the perpendicular distance matters.

Instead of minimizing || bᵢ - aⱼ ||², minimize:

```
( (bᵢ - aⱼ) · nⱼ )²
```

where nⱼ is the **surface normal** at aⱼ (perpendicular to the wall).

**How to get normals?** Fit a line to aⱼ and its neighbors, then take the perpendicular.

Point-to-line converges much faster because it doesn't fight against the "slide along surface" ambiguity.

---

## Part 8: Convergence and Local Minima

### Why Does ICP Converge?

Each iteration consists of:

1. Finding nearest neighbors (correspondences)
2. Computing optimal alignment

Step 2 is a closed-form optimization—it always finds the global minimum for the _current_ correspondences.

After aligning, the total error either:

- Decreases (we found a better alignment), or
- Stays the same (we're at a fixed point)

Since error is bounded below by zero and decreases each iteration, it must converge.

### Local Minima: The Catch

ICP converges to a **local** minimum, not necessarily the global minimum. If the initial guess is bad, it might converge to a wrong alignment.

```
True alignment:   Scans overlap perfectly, error ≈ 0
Local minimum:    Scans partially overlap, error > 0 but stable
```

**Mitigation strategies**:

- Good initial guess (odometry)
- Multiple restarts with different initial guesses
- Branch-and-bound or other global methods (expensive, usually unnecessary)

For your robot with odometry giving a reasonable initial guess, local minima are rarely a problem.

---

## Part 9: Putting It All Together

Here's the complete picture:

```
┌────────────────────────────────────────────────────────────────┐
│  INPUT: Scan A (reference), Scan B (to align), initial guess  │
└────────────────────────────────────────────────────────────────┘
                              │
                              ▼
┌────────────────────────────────────────────────────────────────┐
│  ITERATION LOOP:                                               │
│                                                                │
│  1. Apply current transform to B                               │
│                                                                │
│  2. For each point in B, find nearest neighbor in A            │
│     → Create correspondence pairs                              │
│     → Reject outliers (distance threshold)                     │
│                                                                │
│  3. Compute centroids μ_a, μ_b                                 │
│  4. Center the points: a'ᵢ = aᵢ - μ_a, b'ᵢ = bᵢ - μ_b         │
│  5. Build cross-covariance: H = Σᵢ b'ᵢ · a'ᵢᵀ                 │
│  6. SVD: H = UΣVᵀ                                              │
│  7. Rotation: R = VUᵀ (with reflection check)                  │
│  8. Translation: t = μ_a - R · μ_b                             │
│                                                                │
│  9. Update total transformation                                │
│  10. Check convergence (is transform negligible?)              │
│      If no → repeat from step 1                                │
│      If yes → exit loop                                        │
└────────────────────────────────────────────────────────────────┘
                              │
                              ▼
┌────────────────────────────────────────────────────────────────┐
│  OUTPUT: Final (R, t) that aligns B to A                       │
│          This represents how the robot actually moved          │
└────────────────────────────────────────────────────────────────┘
```

---

## Part 10: Connecting to Your Robot

### Scan in Robot Frame

Your ToF sensor gives readings in polar coordinates relative to the robot:

- Angle: servo position (0° to 180°)
- Distance: ToF reading

Convert to Cartesian (still in robot frame):

```
x = distance · cos(angle)
y = distance · sin(angle)
```

### What ICP Gives You

ICP returns the transformation from scan B to scan A. If:

- Scan A was taken at pose (x₁, y₁, θ₁)
- Scan B was taken at pose (x₂, y₂, θ₂)

Then ICP's (R, t) represents the motion from pose 1 to pose 2.

### Comparison with Odometry

Odometry says you moved (Δx_odo, Δy_odo, Δθ_odo).
ICP says you actually moved (R_icp, t_icp).

The difference is odometry error. You can:

1. Trust ICP completely (replace odometry estimate)
2. Fuse them (use EKF to combine both estimates)

For your slow-moving robot with decent odometry, option 1 often works fine.

---

## Part 11: Testing Strategy

### Test 1: Identity

```
A = B (identical scans)
Expected: R = I, t = [0, 0]
```

If this fails, you have a bug in the basic algorithm.

### Test 2: Pure Translation

```
B = A + [0.1, 0]  (shifted 10cm right)
Expected: t = [0.1, 0], R = I
```

Tests that translation recovery works.

### Test 3: Pure Rotation

```
B = R(15°) · A  (rotated 15°)
Expected: R = R(15°), t = [0, 0]
```

Tests that rotation recovery works. Note: rotation around origin, so t should be zero.

### Test 4: Combined Transform

```
B = R(10°) · A + [0.05, 0.03]
Expected: recover both correctly
```

### Test 5: Gaussian Noise

Add σ = 2cm noise to B (matching your VL53L1X).

```
Expected: Close to true transform, not exact
```

### Test 6: Partial Overlap

Remove 30% of points from each scan (simulating different fields of view).

```
Expected: Still converges (tests outlier handling)
```

### Test 7: Bad Initial Guess

Start with deliberately wrong initial R, t.

```
Expected: Converges if initial error is "small enough"
         May fail if initial error is too large
```

---

## Summary

The key insights to remember:

1. **ICP alternates between correspondence and alignment** because each depends on the other

2. **Alignment is a least squares problem** that minimizes squared error between matched point pairs

3. **Centering decouples rotation from translation**—solve rotation first, translation follows trivially

4. **SVD of the cross-covariance matrix gives the optimal rotation** because it captures the orientational relationship between point sets

5. **Convergence is guaranteed** (to a local minimum) because each step can only decrease error

6. **Good initialization matters** to avoid local minima—use odometry

7. **Outlier rejection prevents bad correspondences** from corrupting the solution

With this understanding, you're ready to implement ICP. Start with the simplest version (point-to-point, distance threshold for outliers), verify with synthetic tests, then add refinements as needed.

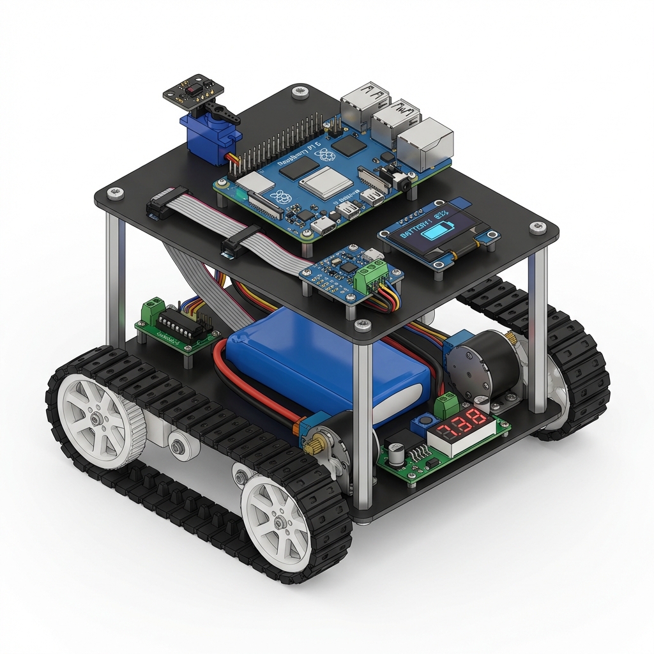
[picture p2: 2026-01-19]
chassis_prototype.png

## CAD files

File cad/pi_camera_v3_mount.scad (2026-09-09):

// Simple mount for custom Camera Module / Sensor
// Updated: Swapped horizontal and vertical camera hole orientation

$fn = 64;

// ---- Target lens center height ----
target_lens_height = 70;

// ---- Camera board mounting pattern (FLIPPED) ----
cam_hole_x   = 20.5;  // horizontal hole spacing
cam_hole_y   = 12.2;  // vertical hole spacing
cam_hole_d   = 2.2;   // M2 clearance
boss_d       = 6;     // camera standoff boss diameter
boss_h       = 3.5;   // standoff height to clear rear components

// ---- Vertical camera face ----
face_margin  = 6;
face_w       = 33;    // matches base width
face_h       = cam_hole_y + 2 * face_margin;   // 24.2mm
face_t       = 3;

// ---- Vertical riser (load-bearing column) ----
riser_w   = face_w;  // 33mm
riser_t   = 5;       // 5mm thickness
overlap   = 0.5;     // overlap for solid geometry merging

// ---- Horizontal mounting flange ----
flange_depth      = 12;   // 12mm depth
flange_t          = 3;
flange_hole_d     = 2.2;  // M2 clearance
flange_hole_inset = 8;    // inset from left/right edges

// ---- Base gussets ----
gusset_t     = 3;

// Calculate riser height:
// target_lens_height = flange_t + riser_h + face_h/2
riser_h      = target_lens_height - flange_t - face_h / 2; // 54.9mm
gusset_reach = min(riser_h, 20); // 20mm vertical leg reach

assert(riser_h > 5, "target_lens_height too small for face_h/flange_t combination");

module camera_face() {
    difference() {
        translate([-face_w/2, 0, 0])
            cube([face_w, face_t, face_h]);

        // Camera mounting holes through face and bosses
        for (dx = [-cam_hole_x/2, cam_hole_x/2])
            for (dz = [-cam_hole_y/2, cam_hole_y/2])
                translate([dx, -1, face_h/2 + dz])
                    rotate([-90, 0, 0])
                        cylinder(d = cam_hole_d, h = face_t + boss_h + 2);
    }

    // Standoff bosses on front face
    for (dx = [-cam_hole_x/2, cam_hole_x/2])
        for (dz = [-cam_hole_y/2, cam_hole_y/2])
            translate([dx, face_t, face_h/2 + dz])
                rotate([-90, 0, 0])
                    difference() {
                        cylinder(d = boss_d, h = boss_h);
                        cylinder(d = cam_hole_d, h = boss_h + 1);
                    }
}

module riser() {
    translate([-riser_w/2, 0, 0])
        cube([riser_w, riser_t, flange_t + riser_h + overlap]);
}

module mount_flange() {
    translate([-face_w/2, 0, 0])
        difference() {
            cube([face_w, flange_depth, flange_t]);

            // Center holes in the exposed flange area in front of the 5mm riser
            for (dx = [flange_hole_inset, face_w - flange_hole_inset])
                translate([dx, (flange_depth - riser_t) / 2, -1])
                    cylinder(d = flange_hole_d, h = flange_t + 2);
        }
}

module gusset(x_pos) {
    hull() {
        translate([x_pos, 0, 0]) cube([gusset_t, 0.01, 0.01]);
        translate([x_pos, flange_depth, 0]) cube([gusset_t, 0.01, 0.01]);
        translate([x_pos, 0, gusset_reach]) cube([gusset_t, 0.01, 0.01]);
    }
}

module camera_mount() {
    mount_flange();
    riser();
    translate([0, 0, flange_t + riser_h])
        camera_face();

    gusset(-riser_w/2);
    gusset(riser_w/2 - gusset_t);
}

camera_mount();

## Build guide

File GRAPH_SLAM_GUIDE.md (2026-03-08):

# Graph SLAM Guide

This guide teaches you pose graph SLAM, building on the scan-matching foundation from [ICM_SCAN_MATCHING.md](ICM_SCAN_MATCHING.md).

> [!IMPORTANT] > **Prerequisite:** You should be comfortable with ICP scan matching (Stage 4) before tackling this. Graph SLAM builds on top of ICP, not as a replacement.

---

## Part 1: Why a Pose Graph?

The current SLAM system works like this:

```
Scan → ICP match against map → Apply correction → Update map → Repeat
```

This is **greedy** — each correction is immediately committed. Two problems:

### Problem 1: Bad ICP = Permanent Damage

```
Step 1: ICP works     Step 2: ICP fails     Step 3: ICP works (but off)
┌──────────┐          ┌──────────┐          ┌──────────┐
│ ■ ■ ■ ■  │          │ ■ ■ ■ ■  │          │ ■ ■ ■ ■  │
│ ■      ■ │   ──►    │ ■      ■ │   ──►    │ ■  ■   ■ │  ← ghost wall!
│ ■  @   ■ │          │ ■    @?  │          │ ■   @  ■ │
│ ■ ■ ■ ■  │          │ ■ ■ ■ ■  │          │ ■ ■ ■ ■  │
└──────────┘          └──────────┘          └──────────┘
     OK                  Drift!               Ghosting!
```

When ICP fails at step 2, the pose drifts. Step 3's scan lands in the wrong place → ghost wall. And it's permanent — there's no undo.

### Problem 2: No Loop Closure

```
Robot explores a loop:

Start → ─ ─ ─ ─ ─ ─ ─ ─ ─ ┐
                             │
                             ↓
  ┌─ ─ ─ ─ ─ ─ ─ ─ ─ End   │
  │                          │
  └ ─ ─ ─ ─ ─ ─ ─ ─ ─ ─ ─ ─┘

End should be at Start, but accumulated drift means
the robot thinks it's 10cm away from where it began.
```

A greedy system has no way to say "I'm back at Start" and fix the whole trajectory.

### The Solution: Defer and Optimize

Instead of immediately committing each ICP correction, **record it as a constraint** and periodically find the set of poses that best satisfies ALL constraints at once.

```
Greedy:    scan → correct → commit (no going back!)

Graph:     scan → record constraint → ... → optimize all at once → rebuild map
```

---

## Part 2: The Pose Graph Structure

### Nodes and Edges

```
    Odometry         Odometry         Odometry
 N0 ═══════════► N1 ═══════════► N2 ═══════════► N3
  ║               ║               ║               ║
  ║   ICP         ║   ICP         ║   ICP         ║
  ╠───(edge)──────╣───(edge)──────╣───(edge)──────╝
  ║                                               ║
  ║              Loop closure                     ║
  ╚═══════════════════════════════════════════════╝
```

**Node** = A pose where the robot stopped and scanned.

- Stores: `(x, y, θ)` + the raw scan data

**Edge** = A constraint saying "the relative pose between these two nodes should be approximately THIS."

- Stores: measured relative transform `(dx, dy, dθ)` + how confident we are

**Three types of edges:**

| Edge | Source | Connects | Confidence |
| --- | --- | --- | --- |
| Odometry | Encoders + IMU | Consecutive nodes | Medium (wheel slip, IMU drift) |
| ICP sequential | Scan-to-scan ICP | Consecutive nodes | Variable (match quality) |
| Loop closure | Scan-to-scan ICP | Distant nodes | High (if ICP succeeds) |

### Why TWO Edges Between Consecutive Nodes?

Odometry and ICP measure the same motion differently. Having both gives the optimizer more information:

- If they agree → high confidence in the transform
- If they disagree → optimizer down-weights the less consistent one

---

## Part 3: Information Matrices (Confidence)

Each edge has an **information matrix** Ω (3×3) that says how much to trust it.

### Intuition: Springs

Think of edges as **springs** connecting nodes:

```
     Stiff spring (high Ω)         Loose spring (low Ω)
     ═══════════════════            ~~~~~~~~~~~~~~~~~~
     "I'm VERY sure about          "I'm not sure about
      this transform"                this transform"
```

When you optimize, you're finding the node positions that minimize the total spring energy. Stiff springs (high confidence edges) dominate.

This is why a bad ICP match doesn't ruin everything: it gets a loose spring, and the optimizer mostly ignores it.

### Building the Information Matrix

For a diagonal information matrix (sufficient for this project):

```
     ┌ 1/σ²_x    0       0    ┐
Ω =  │   0     1/σ²_y     0    │
     └   0       0     1/σ²_θ  ┘
```

Where σ is the standard deviation of the measurement uncertainty.

**Odometry:** σ grows with distance traveled.

```python
σ_x = σ_y = 0.05 * distance_cm   # 5% of distance
σ_θ = 0.02 * abs(rotation_deg)   # 2% of rotation
```

**ICP:** σ depends on match quality.

```python
# Good match (80% ratio, 2cm error) → tight spring
σ_x = σ_y ≈ 0.5 cm
σ_θ ≈ 1°

# Bad match (30% ratio, 8cm error) → loose spring
σ_x = σ_y ≈ 5 cm
σ_θ ≈ 10°
```

---

## Part 4: Optimization with scipy

### What the Optimizer Does

Given:

- Current poses: `[N0, N1, N2, ...]`
- Edges with measurements and information matrices

**Find** adjusted poses that minimize total weighted error:

```
E = Σ (predicted_transform - measured_transform)ᵀ Ω (predicted_transform - measured_transform)
    edge
```

This is a **nonlinear least squares** problem — exactly what `scipy.optimize.least_squares` solves.

### The Residual Function

You provide one function to scipy: `residual(poses_flat)` → returns a vector of errors.

For each edge between node i and node j:

```python
# 1. Extract poses from flat vector
xi, yi, θi = poses_flat[3*i : 3*i+3]
xj, yj, θj = poses_flat[3*j : 3*j+3]

# 2. Predicted relative transform (in node i's local frame)
dx_pred =  cos(θi) * (xj - xi) + sin(θi) * (yj - yi)
dy_pred = -sin(θi) * (xj - xi) + cos(θi) * (yj - yi)
dθ_pred = θj - θi

# 3. Error = predicted - measured
error = [dx_pred - dx_meas, dy_pred - dy_meas, normalize(dθ_pred - dθ_meas)]

# 4. Weight by sqrt of information matrix
weighted_error = sqrt(Ω) @ error
```

Stack all weighted errors into one big vector → return it.

### The normalize() Function

**Critical.** Without it, the optimizer thinks 1° and 359° are 358° apart:

```python
def normalize_angle(θ):
    return (θ + π) % (2π) - π
```

### The Anchor

If every pose can move, the whole graph can slide around while keeping edges happy. Fix node 0 to prevent this:

- Either exclude node 0's variables from the optimization vector
- Or add a very strong "prior" edge pinning it to its initial position

### Huber Loss

`scipy.optimize.least_squares(residual, x0, loss='huber')` automatically down-weights large residuals. This means:

- Normal edges → squared error (standard least squares)
- Outlier edges (bad ICP) → linear error (much less influence)

No special outlier code needed — the loss function handles it.

---

## Part 5: Loop Closure

### Detection

When the robot is near a previously visited position (but many scans ago), that's a loop closure opportunity.

```python
def find_loop_candidates(current_pose, min_gap=10, max_dist=50):
    candidates = []
    for node in graph.nodes:
        if current_node_id - node.id < min_gap:
            continue  # Too recent, skip
        if distance(current_pose, node.pose) < max_dist:
            candidates.append(node.id)
    return candidates
```

### Verification

Run scan-to-scan ICP between the current scan and the candidate's scan. If it converges with good quality → add a loop closure edge.

### The Magic

When a loop closure edge is added and we optimize, the correction **propagates backward** through the entire chain:

```
Before optimization:                After optimization:
N0 ─── N1 ─── N2 ─── N3            N0 ─── N1 ─── N2 ─── N3
                      │                     ↑      ↑      ↑
                loop closure                └──────┴──────┘
                      │             All poses shift slightly to
                      ▼             satisfy the loop closure
                     N0
```

Every node between N0 and N3 shifts a little bit to absorb the error, rather than putting all the correction on one pose.

---

## Part 6: Map Rebuild

After optimization adjusts poses, the occupancy grid is stale (built with old poses). Solution:

```python
def rebuild_map(grid, graph):
    grid.reset()  # Clear to all-unknown
    for node in graph.nodes.values():
        grid.update(node.scan_points, node.pose, free_rays=node.free_rays)
```

This is fast (Bresenham ray tracing) and guarantees a clean map with no ghosting.

When to rebuild: after every optimization call (every 5 scans).

---

## Part 7: Connecting to Your Code

### What Changes

| Component | Before (greedy) | After (graph) |
| --- | --- | --- |
| `_scan_and_update()` | ICP → apply correction → update map | ICP → add edge → (maybe optimize + rebuild) |
| Pose tracking | Modified in-place by ICP | Stored in graph nodes |
| Map | Updated incrementally | Rebuilt from graph after optimization |
| ICP target | Scan vs accumulated map | Scan vs previous scan |

### What Stays the Same

- Scanner, hardware, motion control
- Frontier detection and path planning
- Web UI (just add graph visualization data)
- A\* and occupancy grid internals

### New File Structure

```
src/
├── pose_graph.py          # [NEW] PoseNode, PoseEdge, PoseGraph + optimizer
├── graph_slam_system.py   # [NEW] GraphSlamSystem extends SlamSystem
├── slam_system.py         # [UNCHANGED] Original greedy SLAM (fallback)
├── icp.py                 # [UNCHANGED] Used for scan-to-scan matching
├── occupancy_grid.py      # [UNCHANGED] Rebuilt after optimization
└── ...
```

---

## Part 8: Implementation Order

1. **`PoseGraph` basics** — `add_node()`, `add_edge()`, `get_node()`, properties
2. **Information matrices** — `compute_odometry_info_matrix()`, `compute_icp_info_matrix()`
3. **`_normalize_angle()`** — one line but critical
4. **`_residual()`** — the core optimization function
5. **`optimize()`** — wire up scipy
6. **`rebuild_map()`** — clear + replay
7. **`GraphSlamSystem._scan_and_update()`** — integration
8. **`find_loop_candidates()`** + `_check_loop_closures()` — loop closure
9. **Test with synthetic data** before running on the robot

### Testing Strategy

Start with `pose_graph_test.py`:

```python
# Test 1: Add nodes and edges, verify they're stored correctly
# Test 2: Build a square loop with known transforms, optimize,
#          verify poses form a perfect square
# Test 3: Add one bad edge, verify Huber loss down-weights it
# Test 4: Loop closure — verify backward propagation
# Test 5: rebuild_map — verify grid matches expected
```

---

## Summary

| Concept | What It Means for Your Robot |
| --- | --- |
| **Node** | "I was HERE and saw THIS" |
| **Edge** | "Between HERE and THERE, I measured THIS transform" |
| **Information matrix** | "I'm THIS confident about that measurement" |
| **Optimize** | "Find the poses that make ALL edges happy at once" |
| **Loop closure** | "I'm back where I was 20 scans ago — fix the whole path" |
| **Rebuild** | "Replay all scans at corrected poses for a clean map" |

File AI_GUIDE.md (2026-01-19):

# AI Learning Guide

When helping with this project, prioritize **teaching over implementing**.

## Teaching Approach

### Concepts Before Code

- Start with **why** before **how**
- Use real-world analogies (e.g., "EKF is like a fuzzy blob that grows and shrinks")
- Build intuition before introducing formulas

### Math Instruction

- Explain the **purpose** of an equation before showing it
- Annotate formulas with what each variable means
- Walk through a **concrete numeric example** after the formula
- Connect math back to the robot: "So when your ToF reads 1.5m at 30°..."

### Scaffolded Learning

- Break complex problems into smaller sub-problems
- Ask questions to check understanding before proceeding
- Give algorithm structure and pseudocode, let me write real code
- Suggest what to research rather than providing all answers

### Debugging Support

- Ask what I've observed and what I expected
- Suggest debugging strategies (print statements, visualizations)
- Guide me toward the issue rather than fixing it directly

## When I Ask "How Do I Implement X?"

1. Explain what X does conceptually
2. Break into sub-problems
3. Ask which part is unclear
4. Provide structure for that part
5. Let me write the implementation

## Visuals

Use ASCII diagrams for spatial concepts and coordinate transforms. Draw before you describe.

## Pacing

Don't let me skip stages. If I try to jump ahead, remind me to complete the current stage first. Fundamentals matter.

## Goal

A developer who **understands** robotics, not a repo full of AI-written code.

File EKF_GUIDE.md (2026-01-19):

# Extended Kalman Filter Guide

This guide maps EKF concepts to the RoboTrail robot, distilled from our learning discussion.

> [!IMPORTANT] > **Sensor Sampling vs EKF Update Rate**
>
> Gyros output instantaneous rate (deg/sec), not accumulated rotation. You must sample at 50Hz+ and integrate continuously to capture all motion. The EKF predict/update can run slowly, but **sensor integration must be fast** or you'll miss rotation (aliasing). Same applies to DC motor encoders.

## Why EKF (Not Linear KF)?

Your motion model has **trigonometry**:

```
x_new = x + distance × cos(θ)
y_new = y + distance × sin(θ)
```

The matrix entries depend on the current state θ—that's what makes it **nonlinear**. EKF handles this by recomputing a linearization (Jacobian) at each step.

---

## State, Input, and Measurements

| Element | What It Is | Your Hardware |
| --- | --- | --- |
| **State x** | What we estimate | `[x, y, θ]` (position + heading) |
| **Input u** | What we command | Stepper counts → distance/rotation |
| **Measurements z** | What sensors observe | ToF distances |

### Sensor Roles

| Sensor | Role | Reasoning |
| --- | --- | --- |
| **Steppers** | Input (predict step) | You command them directly |
| **Gyro** | Input (predict step) | Reliable, fast—use directly for θ |
| **Encoders** (DC motors) | Input (predict step) | Treat like stepper counts |
| **ToF** | Measurement (update step) | Corrects position estimate |

> **Key insight**: Gyro as input is simpler than as measurement. The gyro reading directly updates θ in the predict step—no extra Kalman update needed.

---

## The Two Steps

### 1. PREDICT (Motion Update)

Apply physics, then grow uncertainty:

```python
def predict(state, distance, gyro_rotation):
    x, y, theta = state

    # Apply motion model
    x_new = x + distance * cos(theta)
    y_new = y + distance * sin(theta)
    theta_new = theta + gyro_rotation

    # Compute Jacobian F at new state
    F = [[1, 0, -distance * sin(theta_new)],
         [0, 1,  distance * cos(theta_new)],
         [0, 0,  1]]

    # Grow uncertainty
    P_new = F @ P @ F.T + Q

    return [x_new, y_new, theta_new], P_new
```

### 2. UPDATE (Measurement Correction)

Compare expected vs actual sensor reading, then correct:

```python
def update(state, P, tof_distance, servo_angle, map):
    # What should ToF read given our state?
    expected = ray_cast(map, state, servo_angle)
    innovation = tof_distance - expected

    # How does expected reading change with state? (Jacobian)
    H = numerical_jacobian(state, servo_angle, map)  # 1×3

    # Kalman gain: balance prediction vs measurement trust
    R = [[sigma_tof**2]]  # ToF noise
    K = P @ H.T @ inv(H @ P @ H.T + R)

    # Correct state and shrink uncertainty
    state_new = state + K @ innovation
    P_new = (I - K @ H) @ P

    return state_new, P_new
```

---

## Key Matrices

| Matrix | Size | Meaning | How to Set |
| --- | --- | --- | --- |
| **P**  | 3×3 | Current uncertainty  | Starts large, shrinks with measurements |
| **Q**  | 3×3 | Motion uncertainty | Scale by distance moved + angle rotated |
| **R**  | 1×1 (per ToF reading) | Sensor noise | ~2cm for VL53L1X |
| **F**  | 3×3 | Motion Jacobian | Recompute each predict step |
| **H**  | 1×3 (per ToF reading) | Measurement Jacobian | Recompute each update step |
| **K**  | 3×1 | Kalman Gain | Computed from P, H, R |

### Setting Q (Process Noise)

Q scales with how much you moved:

```python
def compute_Q(distance, rotation):
    sigma_trans = 0.01   # 1cm per cm moved
    sigma_rot = 0.02     # ~1° per 10° turned
    sigma_drift = 0.001  # Gyro drift per step

    return np.diag([
        (sigma_trans * abs(distance))**2,
        (sigma_trans * abs(distance))**2,
        (sigma_rot * abs(rotation) + sigma_drift)**2
    ])
```

---

## The H Jacobian: Two Approaches

### Approach A: Scan Matching (Recommended)

Since Stage 4 already uses scan matching, reuse it:

```python
# Scan matcher outputs pose correction (you already have this from Stage 4)
dx, dy, dtheta, covariance = scan_match(scan, map, predicted_pose)

# Use correction as measurement
z = [dx, dy, dtheta]
H = np.eye(3)  # Identity! No Jacobian needed.
R = covariance  # From scan matcher (or tuned constant)
```

**Why recommended**: H is identity (simple!), reuses Stage 4 code, handles data association robustly.

### Approach B: Raw ToF (Educational)

For learning the full EKF, you can use raw ToF readings:

```python
def numerical_H(state, servo_angle, map, eps=1e-4):
    x, y, theta = state
    z0 = ray_cast(map, x, y, theta + servo_angle)

    # Central differences for accuracy
    dz_dx = (ray_cast(map, x+eps, y, theta+servo_angle) -
             ray_cast(map, x-eps, y, theta+servo_angle)) / (2*eps)
    dz_dy = (ray_cast(map, x, y+eps, theta+servo_angle) -
             ray_cast(map, x, y-eps, theta+servo_angle)) / (2*eps)
    dz_dt = (ray_cast(map, x, y, theta+eps+servo_angle) -
             ray_cast(map, x, y, theta-eps+servo_angle)) / (2*eps)

    return [[dz_dx, dz_dy, dz_dt]]
```

**Tradeoff**: More complex (many ray casts for Jacobian), fragile if position estimate is wrong (bad data association).

---

## Processing Multiple ToF Readings

Two valid approaches:

### Sequential (Simpler)

```python
for angle, distance in tof_scan:
    state, P = update(state, P, distance, angle, map)
```

### Batch (More Efficient)

Stack all readings into one update with a 19×3 H matrix and 19×19 R matrix.

Both converge to the same result—use sequential for learning.

---

## Update Frequency

| Phase | When to Run EKF |
| --- | --- |
| **Stop-and-scan** | Predict after each move, update with full scan |
| **Continuous movement** | Predict at 10-50Hz, update whenever ToF has new reading |

---

## When Does EKF Actually Matter?

**Honest assessment for your project:**

| Factor | Your Robot | Impact |
| --- | --- | --- |
| Speed | 2 cm/s | Scan matching easily corrects small errors |
| Sensors | 2 (gyro, steppers) | Little to fuse |
| Runtime | Minutes | Drift doesn't compound much |
| Start position | Known (0,0,0) | No global localization needed |

**Result**: For stop-and-scan at 2 cm/s, Stage 4's simple correction may produce maps nearly as good as EKF. The value of EKF for your project is primarily **educational**.

**When EKF becomes essential**:

- Faster movement (need between-scan tracking)
- More sensors (need proper fusion)
- Longer runs (uncertainty tracking helps detect drift)
- Reliability requirements (graceful degradation)

---

## Variants to Explore

Once basic EKF works:

1. **Gyro as measurement** instead of input—adds redundancy
2. **Velocity in state** `[x, y, θ, v, ω]`—for continuous movement smoothing
3. **Particle filter**—for global localization or symmetric environments
4. **Outlier rejection**—skip measurements with high Mahalanobis distance

---

## Recommended Implementation Order

1. **Predict only**: Just the motion model, no measurements. Watch uncertainty grow.
2. **Fake measurements**: Hardcode expected values to test update step.
3. **Real ToF**: Add actual sensor readings with numerical Jacobian.
4. **Tune Q, R**: Adjust until position estimate is smooth and accurate.
5. **Try scan matching**: Compare robustness vs raw ToF approach.

---

## Common Pitfalls

| Problem | Cause | Fix |
| --- | --- | --- |
| Position "jumps" wildly  | R too small (over-trusting noisy sensor) | Increase R |
| Corrections are too slow | R too large (ignoring sensor) | Decrease R |
| Diverges over time | Q too small | Increase Q |
| Very noisy estimate | Q too large | Decrease Q |
| Map walls don't align | Wrong sensor offset or coordinate transform | Check `scan_point_to_world` |

---

## Quick Reference

```
EKF LOOP:
─────────
1. PREDICT
   state = f(state, motor_input, gyro)  ← Nonlinear physics
   F = Jacobian of f                     ← Linearization
   P = F·P·Fᵀ + Q                        ← Uncertainty grows

2. UPDATE (for each ToF reading)
   expected = ray_cast(state, angle, map)
   innovation = actual - expected
   H = Jacobian of ray_cast              ← Linearization
   K = P·Hᵀ·(H·P·Hᵀ + R)⁻¹              ← Kalman Gain
   state = state + K·innovation          ← Correction
   P = (I - K·H)·P                       ← Uncertainty shrinks

3. Update map with corrected state
4. Plan next move
5. Go to 1
```

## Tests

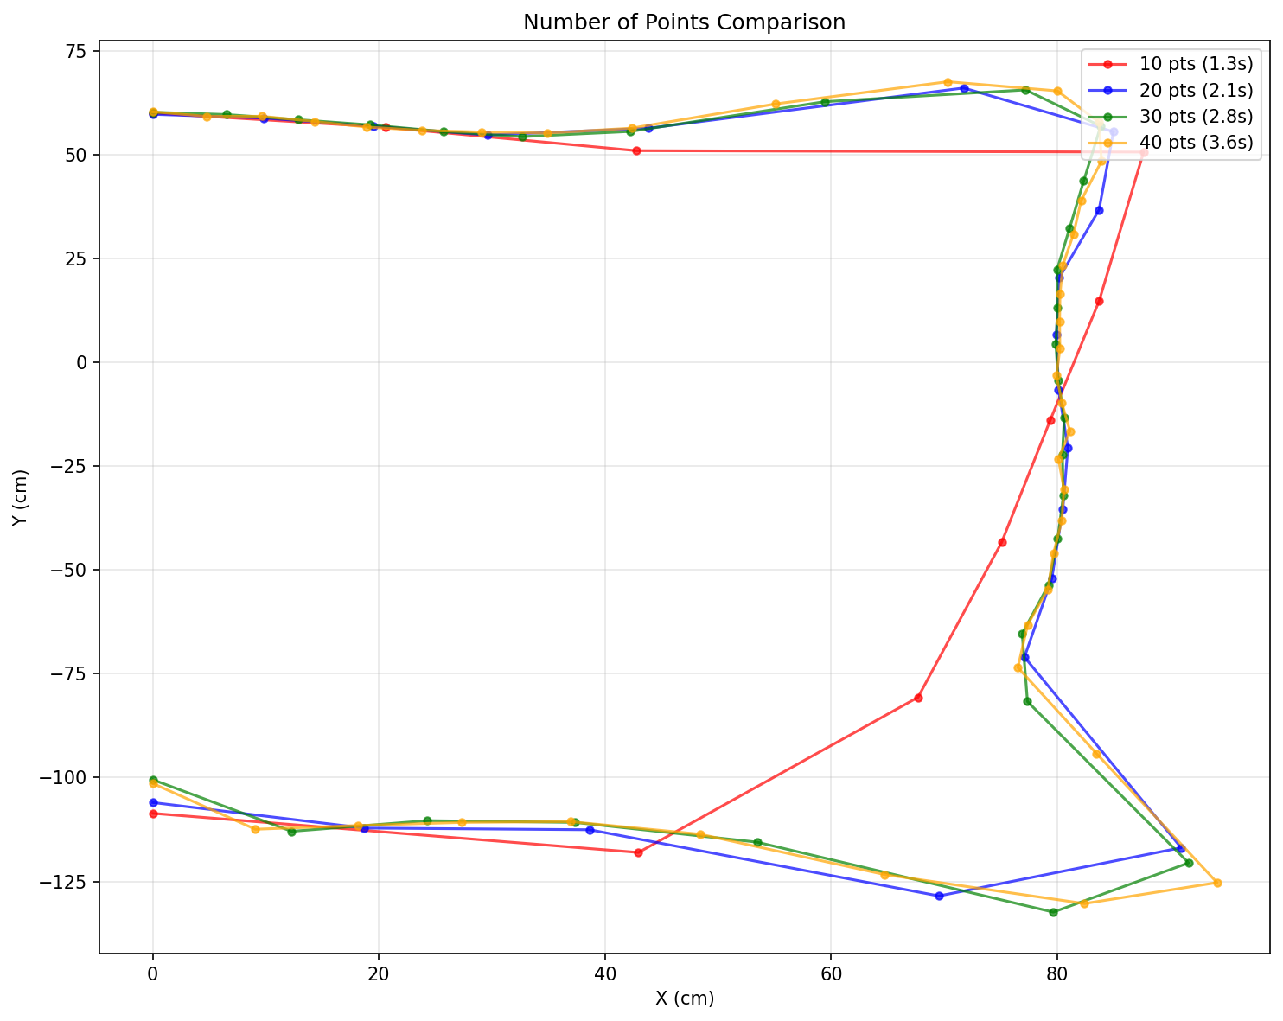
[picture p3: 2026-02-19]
test_num_points.png

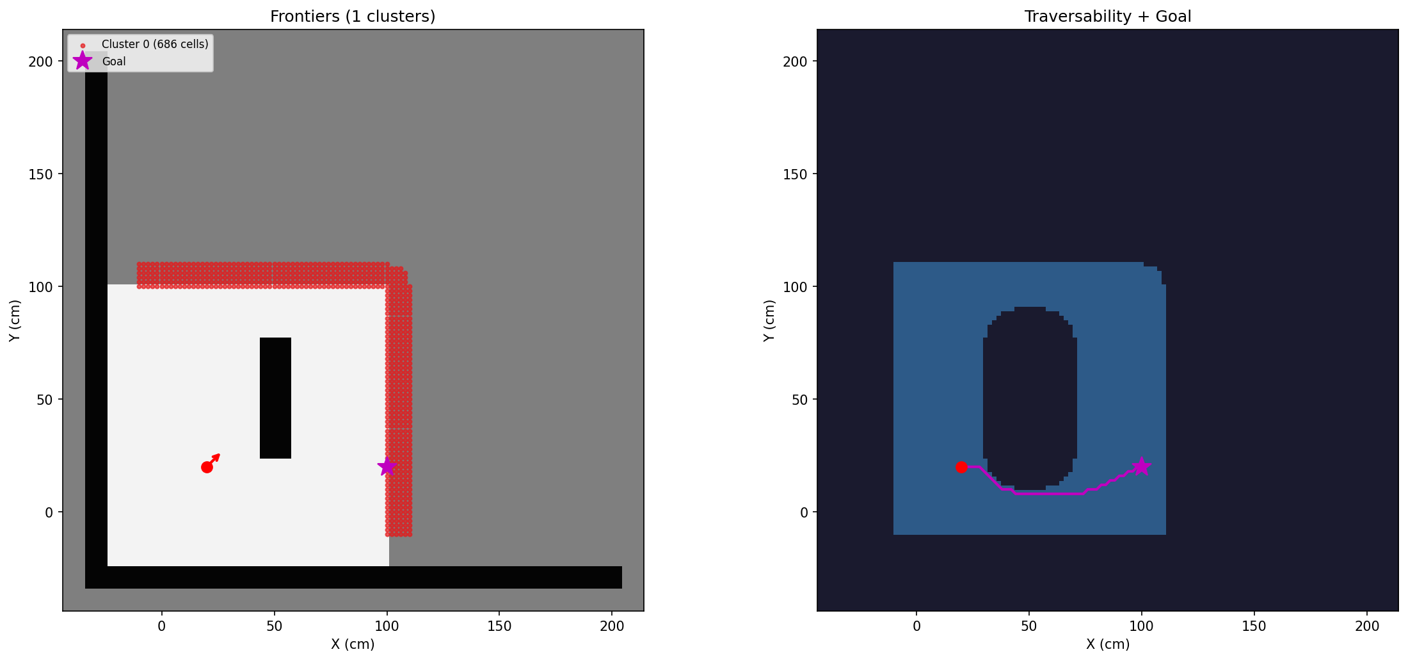
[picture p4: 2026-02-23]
test_frontier.png

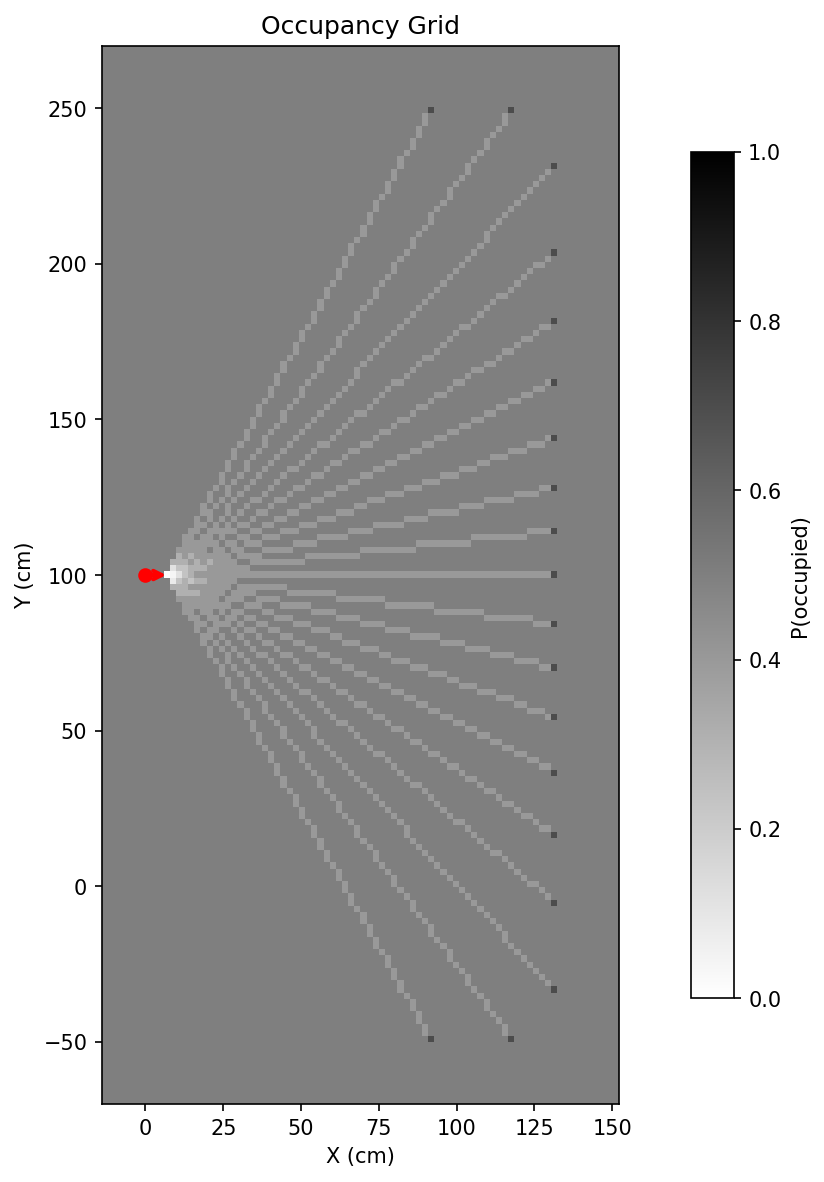
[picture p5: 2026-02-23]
test_occupancy_grid.png

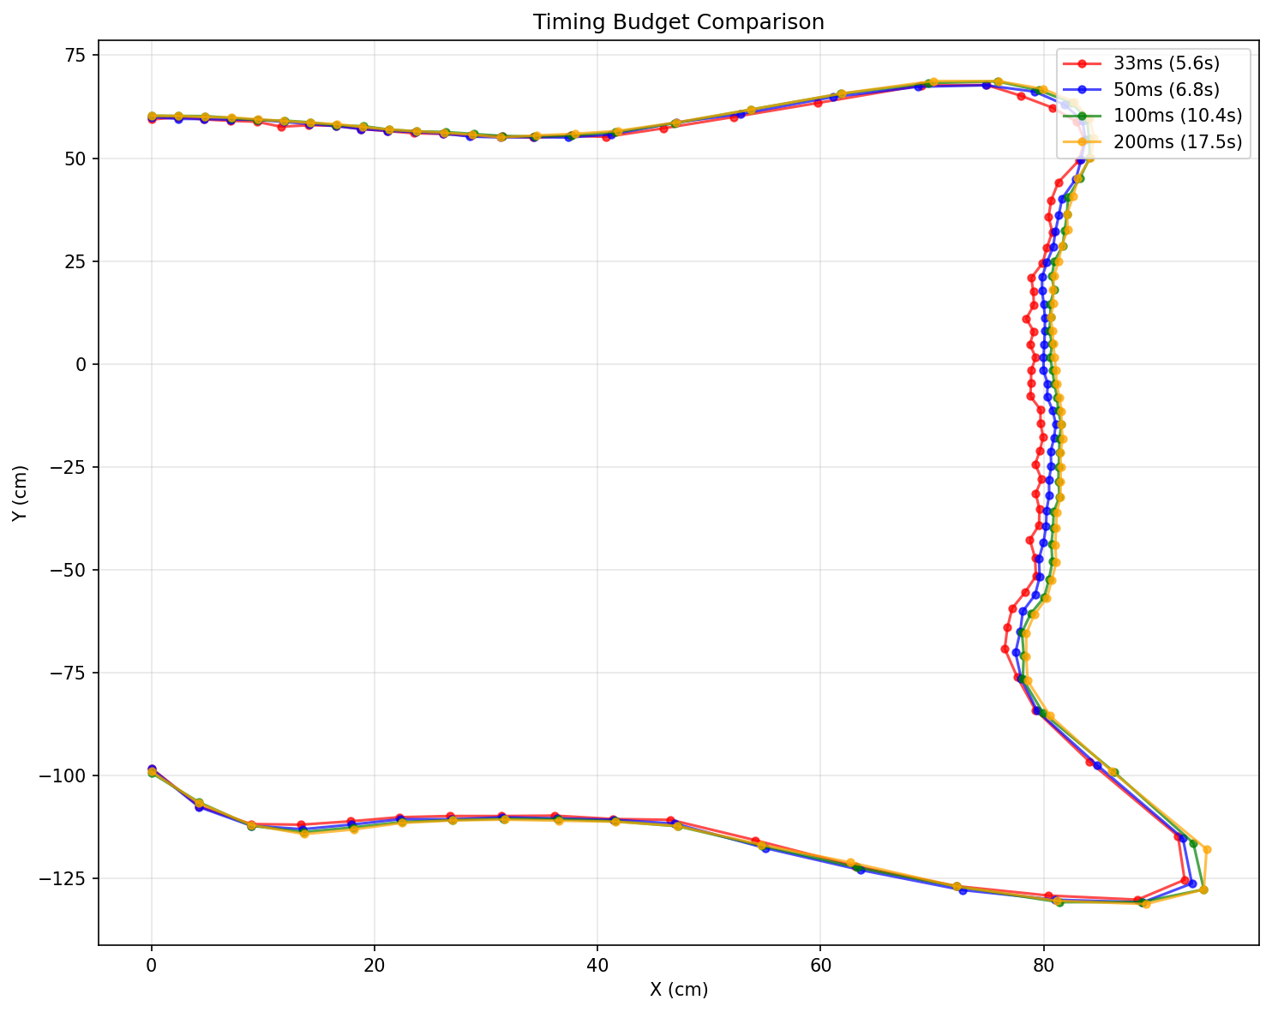
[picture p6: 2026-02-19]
test_timing_budget.png

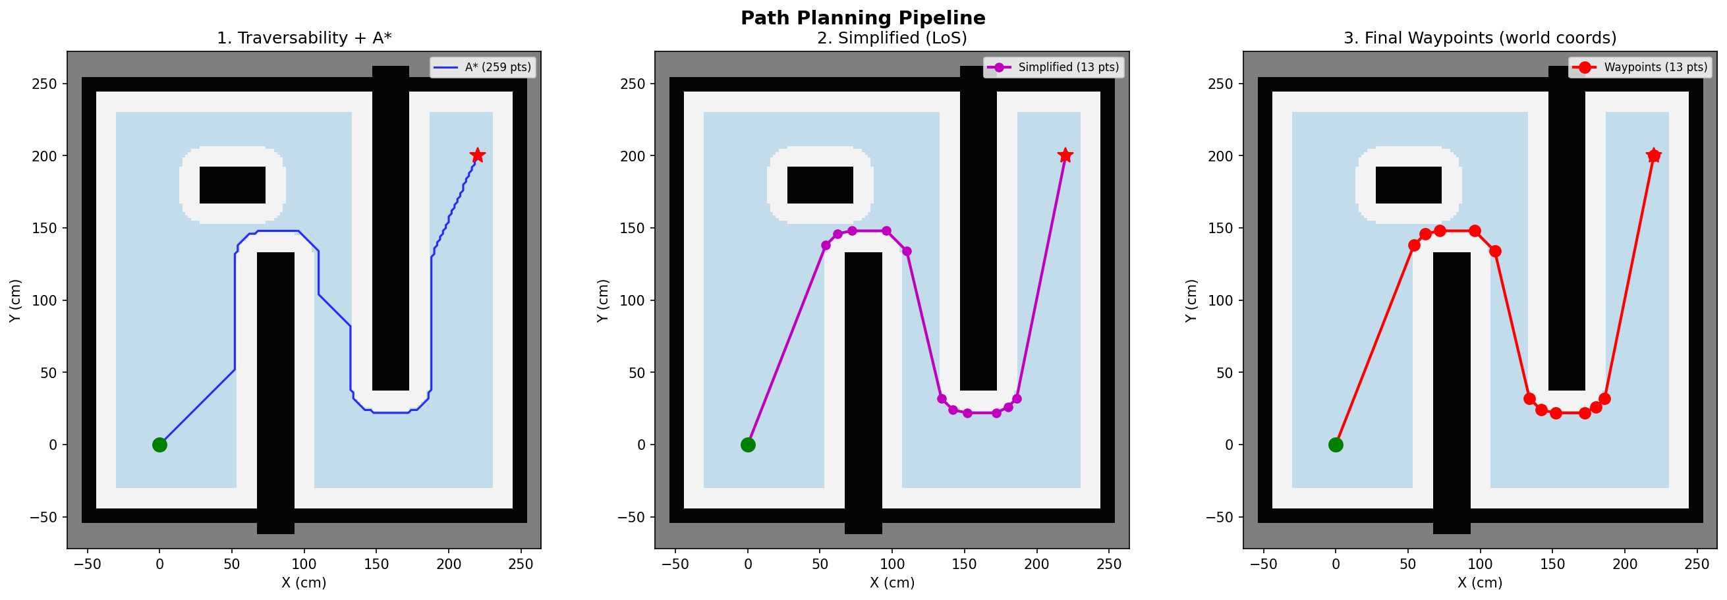
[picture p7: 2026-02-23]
test_path_planner.png

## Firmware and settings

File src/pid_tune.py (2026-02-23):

#!/usr/bin/env python3
"""PID tuning script for DC motor velocity controller.

Ramps target velocity up (like the real velocity profile), cruises,
then ramps down — so the PID is tested under realistic conditions.

Both motors run simultaneously with their own PID+feedforward loops
for realistic chassis load.

Run on Pi:
    python3 pid_tune.py --motor right --kp 0.15
    python3 pid_tune.py --motor left  --kp 0.15 --ki 0.1

Tuning procedure:
  1. Place robot on the floor it will normally navigate.
  2. Start with kp only (ki=0, kd=0).  Look at the cruise phase —
     velocity should track the red target line closely (within 30 ticks/s).
  3. Add small ki (0.01–0.05) to eliminate any steady-state offset
     visible in the cruise phase.
  4. Update PID_KP / PID_KI / PID_KD in config.py when satisfied.
"""

import argparse
import time

import lgpio

from robot.config import (
    DC_LEFT_IN1,
    DC_LEFT_IN2,
    DC_LEFT_PWM,
    DC_RIGHT_IN1,
    DC_RIGHT_IN2,
    DC_RIGHT_PWM,
    FEEDFORWARD_OFFSET,
    FEEDFORWARD_SLOPE,
    PID_KD,
    PID_KI,
    PID_KP,
)
from robot.dc_motor import DCMotor
from robot.pid import PID
from sensors.encoder import Encoder, list_encoder_devices

# ── Config ────────────────────────────────────────────────────────────
CRUISE_VELOCITY = 700  # ticks/sec — match MAX_FORWARD_VELOCITY
DT = 0.02  # 50 Hz — match real control loop
EMA_ALPHA = 0.2  # Must match DCMotorPID._EMA_ALPHA

# Profile timing (total = RAMP + CRUISE)
RAMP_TIME = 1.0  # seconds to ramp 0→cruise
CRUISE_TIME = 4.0  # seconds at full speed


def feedforward(target_velocity: float) -> float:
    """Identical to DCMotorPID._feedforward."""
    if target_velocity == 0:
        return 0
    sign = 1 if target_velocity > 0 else -1
    return sign * (FEEDFORWARD_OFFSET + FEEDFORWARD_SLOPE * abs(target_velocity))


def get_target(t: float) -> float:
    """Trapezoidal velocity profile: ramp up → cruise."""
    if t < RAMP_TIME:
        return CRUISE_VELOCITY * (t / RAMP_TIME)
    return CRUISE_VELOCITY


def run_motor(motor, enc, pid, last_pos, ema_vel, dt, target):
    """One PID+feedforward iteration."""
    pos = enc.position
    raw_vel = (pos - last_pos) / dt if dt > 0 else 0
    ema = EMA_ALPHA * raw_vel + (1 - EMA_ALPHA) * ema_vel
    ff = feedforward(target)
    error = target - ema
    correction = pid.update(error, dt)
    output = max(-100, min(100, ff + correction))
    motor.set_speed(output)
    return pos, ema, output


def main():
    parser = argparse.ArgumentParser(description="PID tuning — wheel velocity")
    parser.add_argument("--motor", choices=["left", "right"], required=True)
    parser.add_argument("--kp", type=float, default=PID_KP)
    parser.add_argument("--ki", type=float, default=PID_KI)
    parser.add_argument("--kd", type=float, default=PID_KD)
    args = parser.parse_args()

    # ── Hardware ──────────────────────────────────────────────────────
    h = lgpio.gpiochip_open(4)
    left_motor = DCMotor(h, DC_LEFT_PWM, DC_LEFT_IN1, DC_LEFT_IN2)
    right_motor = DCMotor(h, DC_RIGHT_PWM, DC_RIGHT_IN1, DC_RIGHT_IN2)

    encoders = list_encoder_devices()
    if len(encoders) < 2:
        print(f"Expected 2 encoders, found {len(encoders)}")
        lgpio.gpiochip_close(h)
        return

    right_enc = Encoder(encoders[0][0])
    left_enc = Encoder(encoders[1][0], reversed=True)

    if args.motor == "right":
        tune_motor, tune_enc = right_motor, right_enc
        companion_motor, companion_enc = left_motor, left_enc
    else:
        tune_motor, tune_enc = left_motor, left_enc
        companion_motor, companion_enc = right_motor, right_enc

    tune_pid = PID(kp=args.kp, ki=args.ki, kd=args.kd)
    companion_pid = PID(kp=PID_KP, ki=PID_KI, kd=PID_KD)

    # ── Data ──────────────────────────────────────────────────────────
    times, target_list, tune_vels, companion_vels, pwms = [], [], [], [], []

    tune_pos = tune_enc.position
    companion_pos = companion_enc.position
    tune_ema = 0.0
    companion_ema = 0.0
    duration = RAMP_TIME + CRUISE_TIME

    print(f"\nTuning {args.motor} motor")
    print(f"  Kp={args.kp}, Ki={args.ki}, Kd={args.kd}")
    print(f"  Profile: ramp {RAMP_TIME}s -> cruise {CRUISE_TIME}s at {CRUISE_VELOCITY}")
    print(f"  Companion: Kp={PID_KP}, Ki={PID_KI}, Kd={PID_KD}")
    print("\nPlace robot on floor, press Enter to start...")
    input()

    last_time = time.monotonic()
    start_time = last_time

    try:
        while (time.monotonic() - start_time) < duration:
            now = time.monotonic()
            dt_actual = now - last_time
            if dt_actual <= 0:
                dt_actual = DT

            t = now - start_time
            target = get_target(t)

            tune_pos, tune_ema, pwm = run_motor(
                tune_motor, tune_enc, tune_pid, tune_pos, tune_ema, dt_actual, target
            )
            companion_pos, companion_ema, _ = run_motor(
                companion_motor,
                companion_enc,
                companion_pid,
                companion_pos,
                companion_ema,
                dt_actual,
                target,
            )

            times.append(t)
            target_list.append(target)
            tune_vels.append(tune_ema)
            companion_vels.append(companion_ema)
            pwms.append(pwm)

            print(
                f"t={t:4.2f}  target={target:5.0f}  tune={tune_ema:6.0f}"
                f"  err={target - tune_ema:+6.0f}  pwm={pwm:5.1f}"
            )

            last_time = now
            loop_time = time.monotonic() - now
            if DT - loop_time > 0:
                time.sleep(DT - loop_time)

    except KeyboardInterrupt:
        print("\nInterrupted")
    finally:
        tune_motor.stop()
        companion_motor.stop()
        tune_enc.close()
        companion_enc.close()
        lgpio.gpiochip_close(h)

    # ── Plot ──────────────────────────────────────────────────────────
    try:
        import matplotlib

        matplotlib.use("Agg")
        import matplotlib.pyplot as plt

        fig, (ax1, ax2) = plt.subplots(2, 1, figsize=(10, 6), sharex=True)

        ax1.plot(times, tune_vels, "b-", label=f"{args.motor} (tuning)")
        ax1.plot(times, companion_vels, "g-", alpha=0.5, label="companion")
        ax1.plot(times, target_list, "r--", label="target")
        ax1.set_ylabel("Velocity (ticks/s)")
        ax1.set_title(
            f"{args.motor.capitalize()} — Kp={args.kp}, Ki={args.ki}, Kd={args.kd}"
        )
        ax1.legend()
        ax1.grid(True)

        ax2.plot(times, pwms, "orange", label="PWM output")
        ax2.set_ylabel("PWM (%)")
        ax2.set_xlabel("Time (s)")
        ax2.legend()
        ax2.grid(True)

        filename = f"pid_tune_{args.motor}_kp{args.kp}.png"
        plt.tight_layout()
        plt.savefig(filename, dpi=100)
        print(f"\nPlot saved: {filename}")
    except ImportError:
        print("\nMatplotlib not available, skipping plot")

    print("Done!")


if __name__ == "__main__":
    main()

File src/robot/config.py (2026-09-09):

"""Robot calibration constants and pin configuration."""

# =============================================================================
# Physical Dimensions (measure your robot)
# =============================================================================
WHEEL_DIAMETER_CM = 4  # Outer diameter of drive wheels
ROBOT_RADIUS_CM = 7.75  # Physical robot radius (155mm diameter / 2)
OBSTACLE_PADDING_CM = 5  # Safety margin added on top of robot radius
# =============================================================================
# DC Motor Pin Configuration (BCM GPIO numbers) - N20 + TB6612FNG
# =============================================================================
# Right motor (TB6612FNG channel A)
DC_RIGHT_PWM = 12
DC_RIGHT_IN1 = 20
DC_RIGHT_IN2 = 21

# Left motor (TB6612FNG channel B) - IN1/IN2 swapped to fix direction
DC_LEFT_PWM = 16
DC_LEFT_IN1 = 25  # Swapped from 24
DC_LEFT_IN2 = 24  # Swapped from 25

# PWM frequency for DC motors (Hz)
DC_PWM_FREQ = 1000

# =============================================================================
# DC Motor Movement Constants
# =============================================================================
TICKS_PER_CM = 49.6  # Calibrate with real measurement
MAX_FORWARD_VELOCITY = 900  # ticks/sec max wheel speed
DT = 0.02  # 50Hz control loop

# Forward motion profile
RAMP_DISTANCE_CM = 5.0  # Ramp up/down over this distance
MIN_SPEED_FACTOR = 0.25  # Minimum speed during ramp (25% of target)

# Turn profile
RAMP_ANGLE_DEG = 12.0  # Ramp up/down over this angle
MAX_TURN_VELOCITY = 650  # ticks/sec max wheel speed during turns
MIN_TURN_FACTOR = 0.35  # Minimum speed during turn ramp (35%)
TURN_PID_FINE_GAIN = 0.1  # 10% of normal heading PID for fine correction

# =============================================================================
# PID Control Constants (Tuned Ziegler-Nichols)
# =============================================================================
# Velocity PID (per motor) - tuned via pid_tune.py
PID_KP = 0.3
PID_KI = 0.1
PID_KD = 0.0

# Feedforward: PWM = OFFSET + SLOPE * velocity
# Calibrated via calibrate_feedforward.py
# OFFSET is the *intercept* of the PWM/velocity line, not the dead-zone PWM:
# at the dead-zone PWM the motor is already turning, so using the raw dead zone
# double-counts. 17.0 ≈ 25% dead zone − 0.065 × ~120 ticks/s at that PWM.
# (Was 4.0, which no run of calibrate_feedforward.py can produce — its search
# starts at 25% — and which left almost no torque at the end of every turn.)
FEEDFORWARD_OFFSET = 17.8  # PWM % intercept
FEEDFORWARD_SLOPE = 0.07  # Measured from 50%→90% PWM tests

# Heading PID (robot level) - TODO: Tune for your robot
HEADING_PID_KP = 30.0  # degrees error → velocity differential
HEADING_PID_KI = 0.5
HEADING_PID_KD = 0.0

# =============================================================================
# Servo/ToF Calibration
# =============================================================================
# Offset to correct servo 0° to true forward (run calibrate_servo_angle.py)
SERVO_ANGLE_OFFSET = 5.9  # degrees (calibrated via calibrate_servo_angle.py)
TOF_OFFSET_X = 6.7  # cm (forward from wheel axis)
TOF_OFFSET_Y = 0.0  # cm (lateral center)

# =============================================================================
# Occupancy Grid
# =============================================================================
GRID_RESOLUTION = 2.0  # cm per cell
GRID_SIZE = 1000  # cells per side (800 × 800 = 16m × 16m at 2cm resolution)
GRID_ORIGIN = 500  # Robot starts at cell (400, 400) = center of grid

# Log-odds update parameters
L_OCC = 0.85  # Added when ray HITS a cell (occupied evidence)
L_FREE = 0.4  # Subtracted when ray PASSES THROUGH a cell (free evidence)
L_MAX = 5.0  # Clamp max (prevents over-confidence)
L_MIN = -5.0  # Clamp min

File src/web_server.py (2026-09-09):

"""Flask web server for SLAM robot control.

Run on Pi: sudo python3 web_server.py
Then open http://<pi-ip> in browser.
"""

import logging
import signal
import subprocess
import sys

from flask import Flask, Response, jsonify, render_template, request

from graph_slam_system import GraphSlamSystem

app = Flask(__name__)
slam = GraphSlamSystem()

CAMERA_CMD = [
    "rpicam-vid",
    "-t", "0",
    "--codec", "mjpeg",
    "--width", "1280",
    "--height", "720",
    "--framerate", "20",
    "--quality", "85",
    "--rotation", "180",
    "--inline",
    "-o", "-",
]


@app.route("/")
def index():
    return render_template("index.html")


def _mjpeg_frames():
    """Run rpicam-vid and split its MJPEG stdout into multipart frames."""
    proc = subprocess.Popen(CAMERA_CMD, stdout=subprocess.PIPE, stderr=subprocess.DEVNULL, bufsize=0)
    buf = b""
    try:
        while True:
            chunk = proc.stdout.read(4096)
            if not chunk:
                break
            buf += chunk
            start = buf.find(b"\xff\xd8")
            end = buf.find(b"\xff\xd9")
            if start != -1 and end != -1 and end > start:
                frame = buf[start : end + 2]
                buf = buf[end + 2 :]
                yield (b"--frame\r\nContent-Type: image/jpeg\r\n\r\n" + frame + b"\r\n")
    finally:
        proc.terminate()
        try:
            proc.wait(timeout=2)
        except subprocess.TimeoutExpired:
            proc.kill()


@app.route("/video_feed")
def video_feed():
    return Response(_mjpeg_frames(), mimetype="multipart/x-mixed-replace; boundary=frame")


@app.route("/api/state")
def get_state():
    """Return pose, status, target."""
    current_pose = slam.robot.get_pose() if slam.robot else slam.pose
    return jsonify(
        {
            "state": slam.state,
            "pose": current_pose,
            "target": slam.target,
            "message": slam.message,
            "map_version": slam.map_version,
            "icp": slam.icp_result,
            "path": slam.path_history,
            "planned": slam.planned_waypoints,
            "icp_corrections": slam.icp_corrections,
            "pid": slam.pid_summary,
            "exploring": slam._exploring,
            "explore_goal": slam.explore_goal,
            "frontiers": slam.frontier_data,
            "graph": getattr(slam, "graph_info", None),
        }
    )


@app.route("/api/map")
def get_map():
    """Return cropped occupancy grid as JSON."""
    return jsonify(slam.get_map_data())


@app.route("/api/target", methods=["POST"])
def set_target():
    data = request.json
    x, y = float(data["x"]), float(data["y"])
    ok = slam.set_target(x, y)
    if ok:
        return jsonify({"status": "ok"})
    return jsonify({"status": "busy"}), 409


@app.route("/api/explore", methods=["POST"])
def start_explore():
    ok = slam.explore()
    if ok:
        return jsonify({"status": "ok"})
    return jsonify({"status": "busy"}), 409


@app.route("/api/explore/stop", methods=["POST"])
def stop_explore():
    slam.stop_explore()
    return jsonify({"status": "ok"})


@app.route("/api/graph")
def get_graph():
    """Return full pose graph data for visualization."""
    if hasattr(slam, "get_graph_data"):
        return jsonify(slam.get_graph_data())
    return jsonify({"error": "Graph SLAM not active"}), 404


def shutdown(sig, frame):
    slam.stop()
    sys.exit(0)


if __name__ == "__main__":
    signal.signal(signal.SIGINT, shutdown)
    slam.auto_explore = True
    slam.start()
    # Suppress per-request access logs from werkzeug
    logging.getLogger("werkzeug").setLevel(logging.WARNING)
    print("Server starting on http://0.0.0.0:80")
    app.run(host="0.0.0.0", port=80, debug=False, use_reloader=False, threaded=True)

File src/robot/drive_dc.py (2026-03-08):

"""High-level robot movement using DC motors with PID control.

Provides intuitive commands: forward(cm), turn(degrees), move_to(x, y),
and follow_path(waypoints).

Motion model: turn-in-place to face target, then drive straight.

Uses trapezoidal velocity profiles for smooth acceleration/deceleration.
"""

import math
from time import monotonic, sleep

from robot.config import (
    DC_LEFT_IN1,
    DC_LEFT_IN2,
    DC_LEFT_PWM,
    DC_RIGHT_IN1,
    DC_RIGHT_IN2,
    DC_RIGHT_PWM,
    DT,
    HEADING_PID_KD,
    HEADING_PID_KI,
    HEADING_PID_KP,
    MAX_FORWARD_VELOCITY,
    MAX_TURN_VELOCITY,
    MIN_SPEED_FACTOR,
    MIN_TURN_FACTOR,
    RAMP_ANGLE_DEG,
    RAMP_DISTANCE_CM,
    TICKS_PER_CM,
    TURN_PID_FINE_GAIN,
)
from robot.dc_motor_pid import DCMotorPID
from robot.pid import PID
from sensors.encoder import list_encoder_devices
from sensors.imu import IMU


class RobotDC:
    """High-level robot control with DC motors and PID."""

    def __init__(self, chip: int):
        """
        Initialize robot with both motors.

        Args:
            chip: lgpio chip handle from gpiochip_open()
        """
        self.chip = chip

        # Find encoder devices
        encoders = list_encoder_devices()
        if len(encoders) < 2:
            raise RuntimeError(f"Expected 2 encoders, found {len(encoders)}")

        # Right encoder is first (GPIO 5/6), Left is second (GPIO 17/27)
        right_enc_path = encoders[0][0]
        left_enc_path = encoders[1][0]

        self.left = DCMotorPID(
            self.chip,
            DC_LEFT_PWM,
            DC_LEFT_IN1,
            DC_LEFT_IN2,
            left_enc_path,
            encoder_reversed=True,
        )
        self.right = DCMotorPID(
            self.chip,
            DC_RIGHT_PWM,
            DC_RIGHT_IN1,
            DC_RIGHT_IN2,
            right_enc_path,
            encoder_reversed=False,
        )

        # IMU and heading control
        self.imu = IMU()  # Calibrates gyro on init
        self.heading_pid = PID(kp=HEADING_PID_KP, ki=HEADING_PID_KI, kd=HEADING_PID_KD)
        self.reset_pose()

        # Data logging for plots
        self.history = []

    # ── Internals ──────────────────────────────────────────────────────

    def _update_heading(self, dt: float) -> float:
        """Update heading from IMU gyro.

        Returns:
            Angular velocity in rad/s (for position update).
        """
        gyro_z = self.imu.read_gyro_z()  # deg/s
        self._heading += gyro_z * dt
        return math.radians(gyro_z)  # rad/s

    def _update_position(
        self, left_vel: float, right_vel: float, omega: float, dt: float
    ) -> None:
        """Update x, y position using RK2 integration.

        Args:
            left_vel: Left wheel velocity in ticks/sec
            right_vel: Right wheel velocity in ticks/sec
            omega: Angular velocity in rad/s (from _update_heading)
            dt: Time step in seconds
        """
        # Linear velocity from encoders
        v = (left_vel + right_vel) / 2 / TICKS_PER_CM  # cm/s

        # RK2: use midpoint heading for curved path
        theta = math.radians(self._heading)
        theta_mid = theta - (omega * dt) / 2  # Go back to midpoint

        # Update position
        self.x += v * math.cos(theta_mid) * dt
        self.y += v * math.sin(theta_mid) * dt

    def _log(self, t, left_vel, right_vel, left_pwm, right_pwm, heading_error, diff):
        """Append a data point to history."""
        self.history.append(
            {
                "t": t,
                "left_vel": left_vel,
                "right_vel": right_vel,
                "left_pwm": left_pwm,
                "right_pwm": right_pwm,
                "heading": self._heading,
                "heading_error": heading_error,
                "heading_diff": diff,
            }
        )

    @staticmethod
    def _speed_factor(
        progress: float, total: float, ramp: float, min_factor: float
    ) -> float:
        """Compute trapezoidal speed factor based on progress.

        Args:
            progress: How far along (cm or degrees traveled).
            total: Total distance/angle to cover.
            ramp: Ramp distance/angle for acceleration and deceleration.
            min_factor: Minimum speed factor (0..1).

        Returns:
            Speed multiplier between min_factor and 1.0.
        """
        if total <= 2 * ramp:
            # Short move: triangle profile (no cruise phase)
            half = total / 2
            if progress < half:
                frac = progress / half if half > 0 else 1.0
            else:
                frac = (total - progress) / half if half > 0 else 1.0
            return min_factor + (1.0 - min_factor) * frac

        # Normal trapezoidal: ramp up → cruise → ramp down
        remaining = total - progress
        if progress < ramp:
            frac = progress / ramp
            return min_factor + (1.0 - min_factor) * frac
        elif remaining < ramp:
            frac = remaining / ramp
            return min_factor + (1.0 - min_factor) * frac
        else:
            return 1.0

    # ── Movement Commands ──────────────────────────────────────────────

    def forward(self, cm: float, velocity: float = MAX_FORWARD_VELOCITY) -> None:
        """Drive forward with trapezoidal velocity profile and heading hold.

        Ramps up over the first RAMP_DISTANCE_CM, cruises, then ramps down
        over the last RAMP_DISTANCE_CM. Heading PID maintains straight line.

        Args:
            cm: Distance in centimeters (negative = backward).
            velocity: Peak speed in ticks/sec.
        """
        target_ticks = abs(cm) * TICKS_PER_CM
        total_cm = abs(cm)
        direction = 1.0 if cm >= 0 else -1.0
        print(f"Forward {cm:+.1f}cm (heading={self._heading:.1f}°)")

        self.left.reset()
        self.right.reset()
        self.heading_pid.reset()
        target_heading = self._heading

        t = 0.0
        last_time = monotonic()
        while True:
            avg_ticks = (abs(self.left.position) + abs(self.right.position)) / 2
            if avg_ticks >= target_ticks:
                break

            now = monotonic()
            dt_actual = now - last_time
            last_time = now

            omega = self._update_heading(dt_actual)

            # Velocity profile
            progress_cm = avg_ticks / TICKS_PER_CM
            factor = self._speed_factor(
                progress_cm, total_cm, RAMP_DISTANCE_CM, MIN_SPEED_FACTOR
            )
            vel = direction * velocity * factor

            # Heading correction (PID for straight-line hold)
            heading_error = target_heading - self._heading
            diff = self.heading_pid.update(heading_error, dt_actual)

            left_vel, left_pwm = self.left.update(vel - diff)
            right_vel, right_pwm = self.right.update(vel + diff)
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

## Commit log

2026-01-19 Added sensor test scripts, tof+servo calibration
2026-01-20 Added motors and calibration scripts
2026-01-20 added imu wrapper an improved motor calibration to use imu sensor
2026-01-20 parallel motor steps
2026-01-20 updated calibrate script to use scanner
2026-01-20 more calibration scripts
2026-01-23 updated readme to describe encoders
2026-01-25 updated readme and scripts to account for true directions; dc motor scripts
2026-01-25 servo angle offset calibration
2026-01-25 Added encoder class and tests
2026-01-26 PID and dc motors and test scripts
2026-01-26 impvorinv pid tuning
2026-01-26 tuned pid
2026-01-27 Final DC pid classes and test script
2026-01-27 imu heading pid
2026-01-27 Feedforward PID
2026-01-27 fixed calibration script
2026-01-27 calibrated feedforward
2026-01-27 added clamping
2026-01-28 calibrated 0 servo-tof direction
2026-01-28 added config for 0 tof-servo heading
2026-01-29 estimate odometry and pose
2026-01-29 added max velocity calculation
2026-01-29 Fixed sensor coordinate system and offset
    [config.py, icp_test_real.py, scanner.py]
2026-01-29 attempting to fix ICP matching in test script
    [scanner.py]
2026-02-15 re-calibrate gyro, better map visual
2026-02-15 set_path, path visualization, pid visualization
2026-02-17 turn when heading difference is too big
    [slam_system.py]
2026-02-17 trying to fix movemenst issues
    [slam_system.py]
2026-02-18 calibrate dc script, point-to-line ICP, path following
2026-02-19 Fixed issue with scan to world, more robust icp
    [icp.py, occupancy_grid.py, slam_system.py]
2026-02-19 Improved scanning performance and stability
    [scanner.py, servo.py]
2026-02-19 smoothed out encoder velocity readings
2026-02-19 trying to fix stuck robot
    [frontier.py, slam_system.py]
2026-02-23 fixed pid tune script
    [pid_tune.py]
2026-02-23 fixed feedforward calibration - added settle duration
    [calibrate_feedforward.py]
2026-02-23 improving pid tune script
2026-02-24 Updated to improve stability of ICP scan
    [calibrate_servo_angle.py, drive_dc.py, slam_system.py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]
2026-02-24 fixed bug with infinite rotation
    [slam_system.py]
2026-02-24 fix stuck robot again
    [slam_system.py]
2026-03-05 fixing infinite rotation bug
    [config.py, drive_dc.py]
2026-03-08 graph slam bug fixes
    [graph_slam_system.py, pose_graph.py]
2026-03-08 fixing active loop closure
    [graph_slam_system.py]
2026-03-08 trying to fix drift
    [graph_slam_system.py]
2026-09-09 Re-calibrate, more stable mapping
2026-09-09 pi cam mount scad
    [pi_camera_v3_mount.scad]
2026-09-09 Pi camera recording
